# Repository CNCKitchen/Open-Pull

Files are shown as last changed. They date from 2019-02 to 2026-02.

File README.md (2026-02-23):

# Open-Pull

DIY universal testing machine files (mechanics, electronics, firmware, and browser control UI).

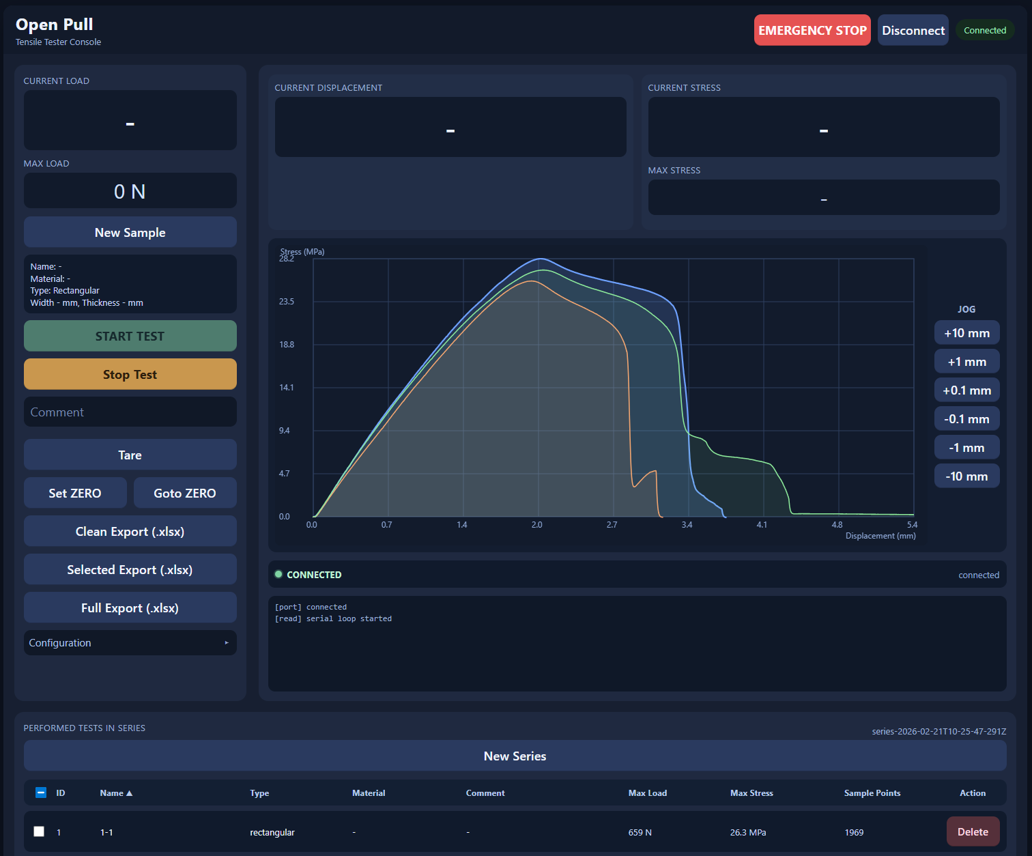
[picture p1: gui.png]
Open-Pull Web GUI


Watch the project video: https://youtu.be/uvn-J8CbtzM

Support: [Patreon](https://www.patreon.com/cnckitchen) · [PayPal](https://www.paypal.me/CNCKitchen)

## Safety + Disclaimer

Open-Pull is a DIY machine and **not certified professional test equipment**.

- Use safety glasses and shielding.
- Keep hands, loose clothing, and tools away from moving parts.
- Verify load limits for frame, grips, motors, drivers, and load cell.
- Validate calibration before collecting any meaningful data.

You are responsible for safe operation and for verifying all measurements.

## Repository Contents

- `Arduino/OpenPull/OpenPull.ino` – firmware for Arduino Nano-compatible target.
- `WebGUI/` – browser-based control and data export app (Web Serial).
- `Electronics/Eagle-Files/` – schematic/board files and custom Eagle library.
- `CAD/TestMachine/` – machine assembly files (`.f3d`, `.step`) and parts.
- `CAD/Specimens/` – specimen CAD models.
- `Documents/DataAnalysis.xlsx` – spreadsheet-based analysis template.
- `Documents/exportTrackingPoints.py` – Blender tracking marker export helper.

## Hardware Overview

Typical build components include:

- 2× geared NEMA17 steppers
- 2× trapezoidal lead screws and nuts
- linear guidance/bearings/couplers/frame hardware
- Arduino Nano
- 2× A4988 stepper drivers
- HX711 load-cell amplifier + suitable load cell
- 24V supply and cooling

Use the CAD and electronics folders as the source of truth for your specific build variant.

## Firmware

Firmware location: `Arduino/OpenPull/OpenPull.ino`

### Key behavior

- Non-blocking serial command handling.
- Timer-driven step generation.
- Ramped acceleration/deceleration.
- Median + exponential filtering for load values.
- Automatic break detection (optional) with optional quick re-tare.
- Persistent config in EEPROM (speeds, accel, gain, sample rate, etc.).

### Firmware dependencies

- Arduino `HX711` library by Bogde (`bogde/HX711`).
- Arduino `EEPROM` (built-in).

### Upload basics

1. Open `Arduino/OpenPull/OpenPull.ino` in Arduino IDE.
2. Select your board/port.
3. Ensure the HX711 library is installed.
4. Compile and upload.

Serial settings: **115200 baud**, newline-terminated commands.

## Command Reference

All commands are ASCII lines terminated with `\n`.

### Motion + test control

- `M10 [S1]` – start slow test. `S1` enables slow-test break-speedup mode.
- `M11` – manual mode / stop active test.
- `M12` – tare load cell.
- `M13` – Young's/modulus profile (slow phase then fast phase).
- `M14` – start fast test.
- `M15` – emergency stop.
- `M20` – set current position as displacement zero.
- `M21` – move to displacement zero.
- `M22 <delta_mm>` – relative jog move.

### Configuration

- `M40 <mm_per_min>` – set slow test speed.
- `M41 <mm_per_min>` – set fast test speed.
- `M42 <mm_per_s2>` – set acceleration.
- `M43 <gain>` – set load-cell gain (**only during unlocked gain window**).
- `M44 <Hz>` – set sample rate.
- `M45 <mm_per_min>` – set manual slow jog speed.
- `M46 <mm_per_min>` – set manual fast jog speed.
- `M47 <N>` – set preload target for slow-test start sequence.
- `M48 <0..1>` – set load filter alpha.
- `M49 <0|1>` – disable/enable auto break detection.
- `M50` – report current config.
- `M51 <0|1>` – disable/enable tare-after-break.
- `M53` – arm gain write window (30s wait + 30s allowed write window).

## Serial Protocol

Firmware emits CSV-like tagged lines:

- `DATA,<timestamp_ms>,<load_N>,<step_position>,<displacement_mm>,<mode>,<speed_steps_per_s>`
- `STATUS,<timestamp_ms>,<code>,<message>`
- `ACK,<timestamp_ms>,<command>,<message>`
- `CFG,<timestamp_ms>,<slow_mm_min>,<fast_mm_min>,<accel_mm_s2>,<gain>,<sample_hz>,<manual_slow_mm_min>,<manual_fast_mm_min>,<preload_n>,<alpha>,<auto_break>,<tare_after_break>`

Mode values:

- `1` slow test
- `2` manual
- `3` fast test
- `4` Young's test
- `5` go-to-zero
- `6` relative move

## Web GUI

GUI location: `WebGUI/index.html`

### Features

- Web Serial connect/disconnect.
- Guided workflow: create series → prepare sample → start test.
- Clean status row with color-coded state indicator (e.g. ready, pretension, moving to zero, testing, break detected, test stopped) and detailed status text.
- Live chart with selectable axes:
	- X: time or displacement
	- Y: force or stress
- Per-test metadata (name/material/comment/type/geometry).
- Performed-tests table with sortable columns: ID, name, type, material, comment, max load, max stress, sample points.
- Per-test delete action in the series list.
- Overlay management via per-test checkboxes + master checkbox (all eligible tests on/off).
- Duplicate-name warning when preparing a new sample.
- Manual jog buttons (`±0.1`, `±1`, `±10 mm`).
- Tare, zero, goto-zero, stop, and emergency stop.
- Firmware config controls (preload, alpha, sample rate, manual speeds, accel, gain unlock/set, break options).
- Export to XLSX (clean, selected, and full variants), each with configuration and summary data.
- Local persistence of series state in browser `localStorage`.

### Browser requirements

- Chromium-based browser with Web Serial support (Chrome/Edge).
- USB serial permission to the controller.
- Internet connection if loading the bundled CDN XLSX script as-is.

### Running

1. Open `WebGUI/index.html` in a compatible browser.
2. Click **Connect** and choose the Open-Pull serial port.
3. Click **New Series**.
4. Click **New Sample**, fill sample details, confirm.
5. Set speed/config as needed.
6. Click **START TEST**.
7. Stop with **Stop Test** (`M11`) or **EMERGENCY STOP** (`M15`) if required.
8. Export results with **Clean Export (.xlsx)**, **Selected Export (.xlsx)**, or **Full Export (.xlsx)**.

## Data Export

WebGUI provides three spreadsheet exports:

- **Clean Export (.xlsx)**
	- Organized two-column blocks per test (displacement vs stress/force)
	- Uses the current series-list sort order
	- Includes `Summary` and `Configuration` sheets
	- Intended for quick plotting and reporting

- **Selected Export (.xlsx)**
	- Same layout as clean export, but only for tests selected in the series list checkbox column
	- Uses the current series-list sort order
	- Includes `Summary` and `Configuration` sheets

- **Full Export (.xlsx)**
	- Flat table with full per-sample rows
	- Includes timestamps, load, displacement, mode, speed, and metadata
	- Includes `Summary` and `Configuration` sheets

The `Summary` sheet mirrors the performed-tests overview (ID, name, type, material, comment, max load, max stress, sample points).

`Documents/DataAnalysis.xlsx` can be used for additional analysis workflows.

## Optical Tracking Helper

`Documents/exportTrackingPoints.py` exports Blender tracking marker coordinates to CSV files.

Update the output path inside the script to match your system before running.

## Troubleshooting

- **No serial connection in browser:** use Chrome/Edge and verify Web Serial support/permissions.
- **`hx711_not_ready` status:** check HX711 wiring, power, and load-cell connection.
- **Cannot set gain:** send/use `M53`, wait for unlock delay, then send `M43 <gain>` within the allowed window.
- **Unexpected force spikes/noise:** verify grounding, shielded wiring, stable power, and tuning of filter alpha/sample rate.
- **Inconsistent displacement zero:** run `M20` at known reference and use `M21` for repeatability checks.

## License

This repository is licensed under **GNU GPL v3.0**. See `LICENSE`.

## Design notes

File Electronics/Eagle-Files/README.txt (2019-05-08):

Version 1:
Carrier PCB for:
	- Arduino Nano,
	- Sparkfun HX711 Weight Cell Amplifier
	- 2x Polulu Stepper Motor Driver
	- 2x 100uF smoothing Capacitor for Stepper Motor Drivers either SMD or THT
	- a on board sync-led either THT or SMD
	- IMPORTANT NOTICE: this is the 1st version of the board and may still contain errors!!! 
	  ALSO: only use either an SMD or a THT capacitor same goes for the onboard LED.
	
Parts:
	- Arduino Nano: original or clone will do
	- Sparkfun HX711: https://www.sparkfun.com/products/13879
	- Polulu A4988 Stepper Motor Drivers: https://www.pololu.com/product/1182
	- R1/R2: 330 Ohm Resistor: 1/4W THT or 0805 SMD
	- LED1/LED2: 3.5mm LED or 0805 LED color doesn't matter (ajust resistor for blue)
	- C1/C3 & C2/C4: Any fitting Capcitor will do, I designed around these:
			- THT: WURTH ELECTRONIC 860020674015
			- SMD: WURTH ELECTRONIC 865060653010
	- CELL-0, 1, 2, X1: WURTH ELECTRONIC 691214110002
	- CON1, CON2, CON3: Any 100mil/1.27mm pitch connector that fits your needs. You can als solder directly into the holes.

Board by Felix Hillebrand 97hilfel(at)gmail.com
Feel free to use and share.

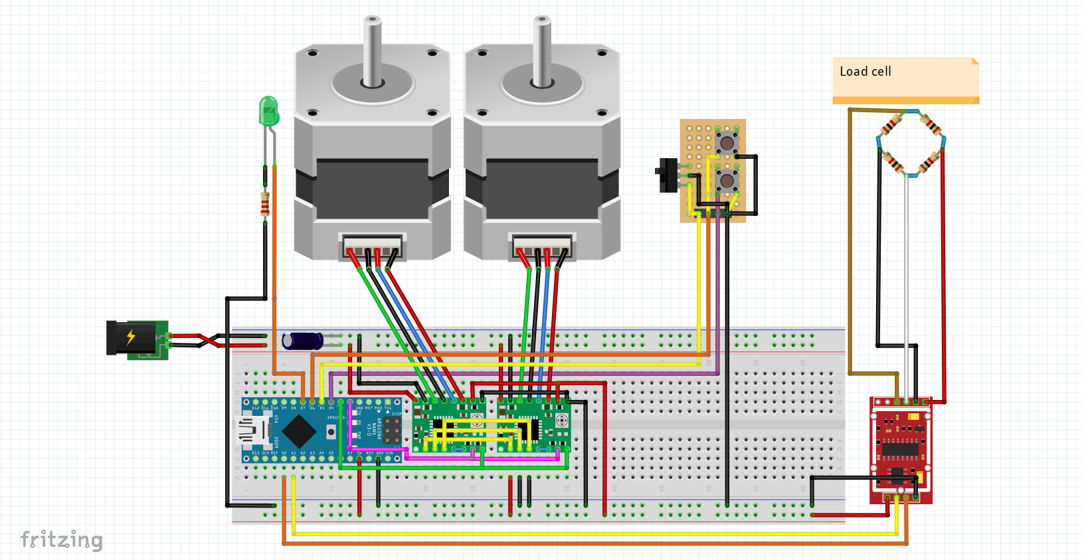
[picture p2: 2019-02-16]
Electronics/schematics.png

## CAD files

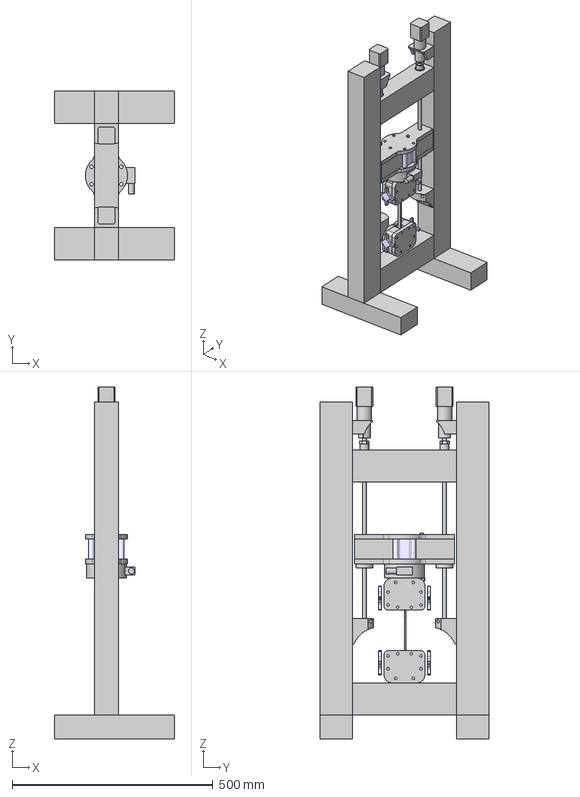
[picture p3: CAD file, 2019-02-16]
CAD/TestMachine/OpenPull-assembly.step
300.0 x 420.0 x 877.0 mm
SpecimenHolder_OuterPart x 2
ClampingPlate x 4
einschlagmutter_M8 x 2
SpecimenHolder_OuterPart (1) x 2
Knob x 2
608 bearing x 4
TestSpecimen_ISO-527-2-1A
nut_flange x 2
leadScrew x 2
Clutch x 2
nut x 2
stepper x 2
stepperBracket x 2
lowerBearing x 2
3200 2RS - bearing x 2
6202-Z bearing x 2
trapezoidalNut1 x 2
trapezoidalNut2 x 2
upperMemberSupport (1)
upperMember
upperMemberSupport
loadCell
M8x120
spacer x 2
foot x 2
sidePillars x 2
mostUpperMember
lowerMember

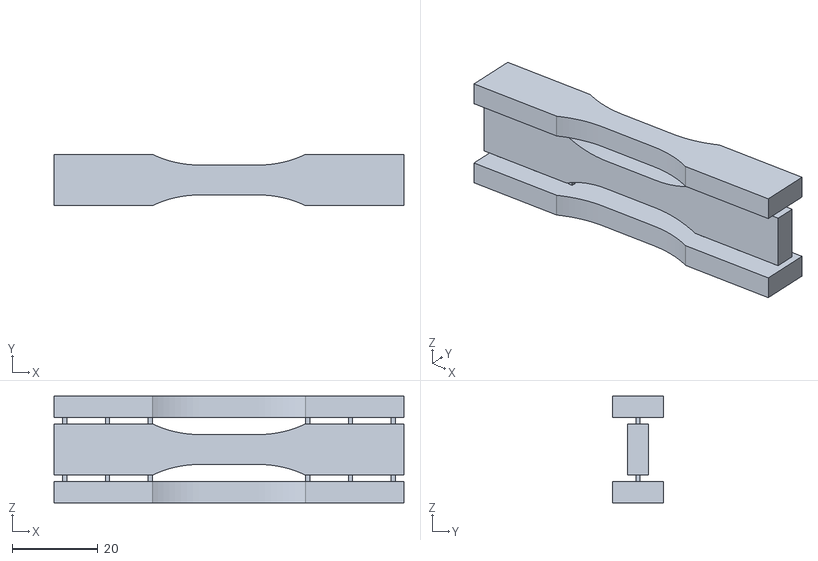
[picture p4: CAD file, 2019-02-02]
CAD/Specimens/TensileSpecimen_LayerAdhesion_x3.stl
81.8 x 12.0 x 25.0

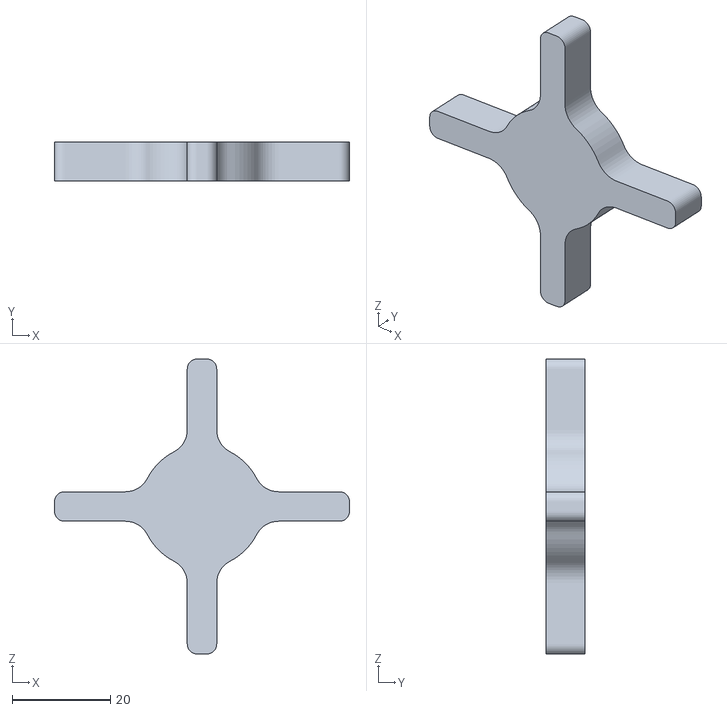
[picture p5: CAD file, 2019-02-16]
CAD/TestMachine/IndividualParts/TensileTestMachine v6_TensileTestMachine v6_ClampingYaw1_1_Knob_1_Body1_Knob_1.stl
60.0 x 8.00 x 60.0

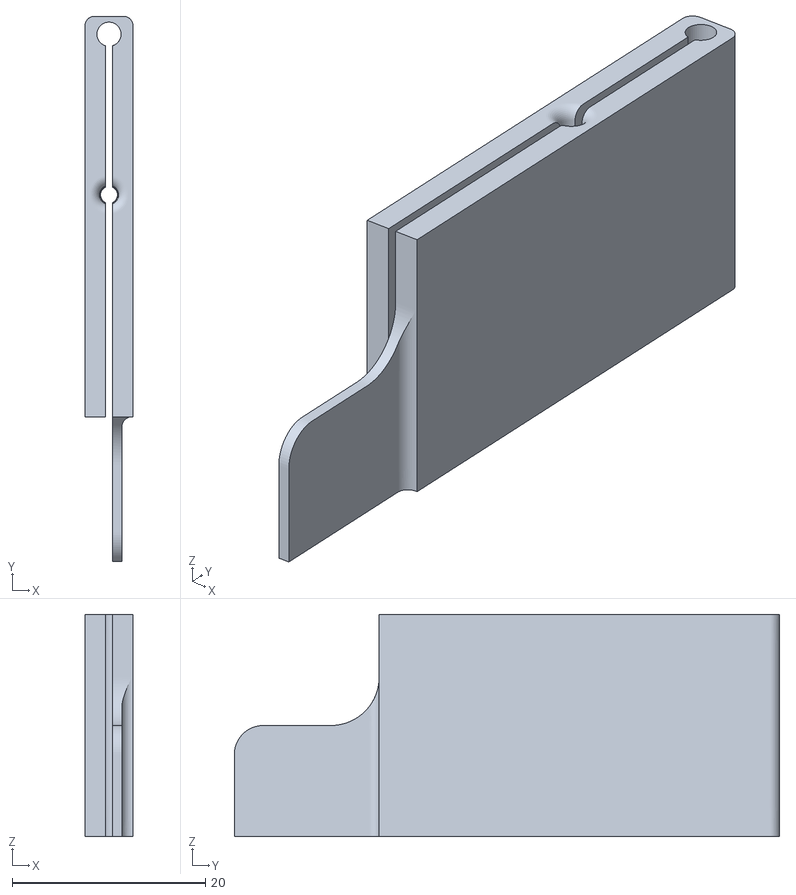
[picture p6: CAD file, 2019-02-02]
CAD/Tools/FilamentClamp.stl
5.00 x 56.5 x 23.0

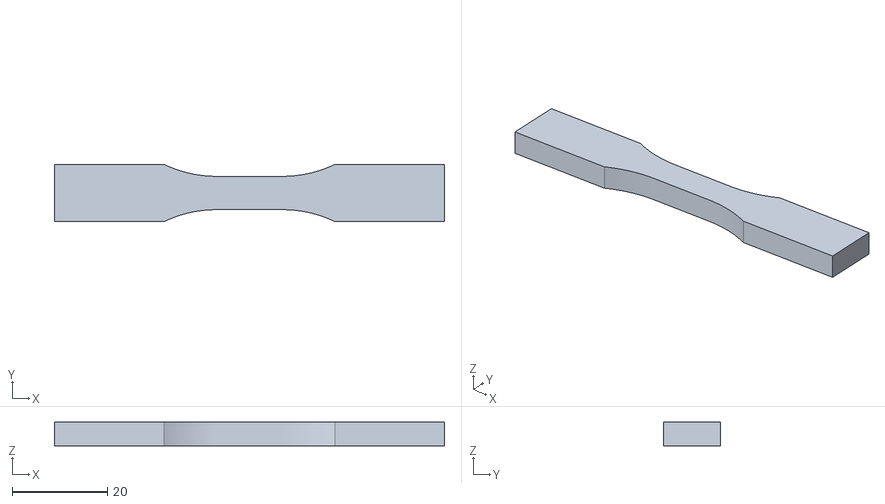
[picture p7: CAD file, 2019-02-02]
CAD/Specimens/TensileSpecimen_LayerAdhesion.stl
81.8 x 12.0 x 5.00

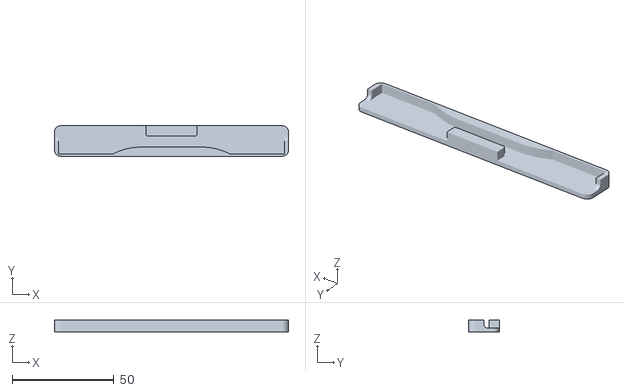
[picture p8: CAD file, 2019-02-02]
CAD/Tools/DistanceGauge.stl
115.0 x 15.0 x 6.00

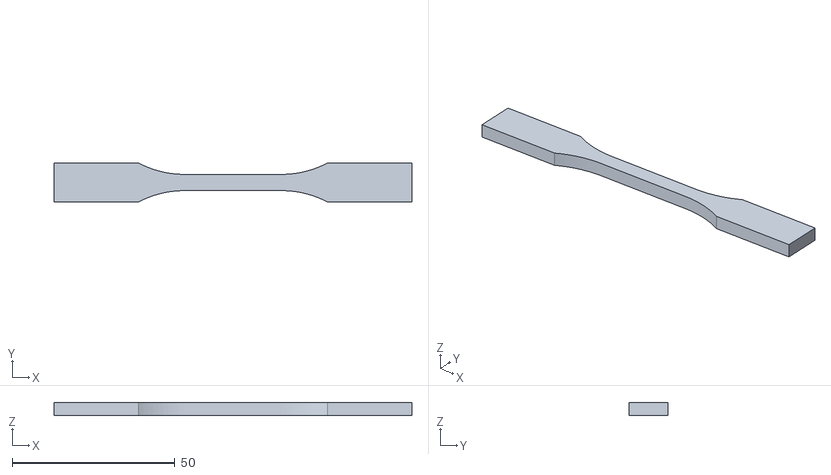
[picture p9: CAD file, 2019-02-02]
CAD/Specimens/TensileSpecimen_ISO-527-2-1BA.stl
110.0 x 11.9 x 4.00

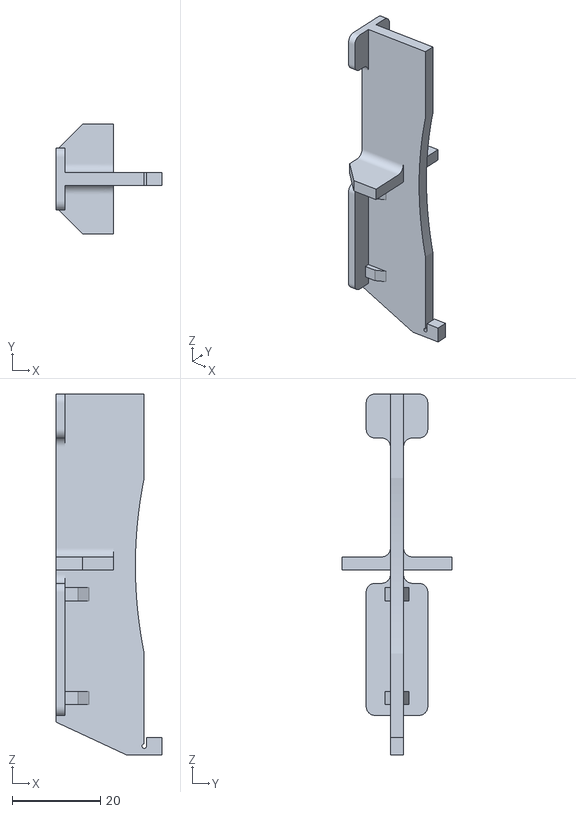
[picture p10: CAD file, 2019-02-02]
CAD/Tools/LayerAdhesionSpecimenAlignmentTool.stl
24.0 x 25.0 x 82.0

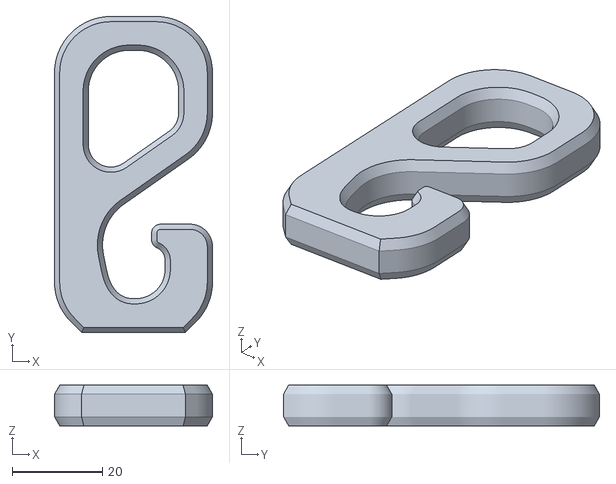
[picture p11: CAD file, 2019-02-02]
CAD/Specimens/testHook_noSlots.stl
35.0 x 70.0 x 9.00

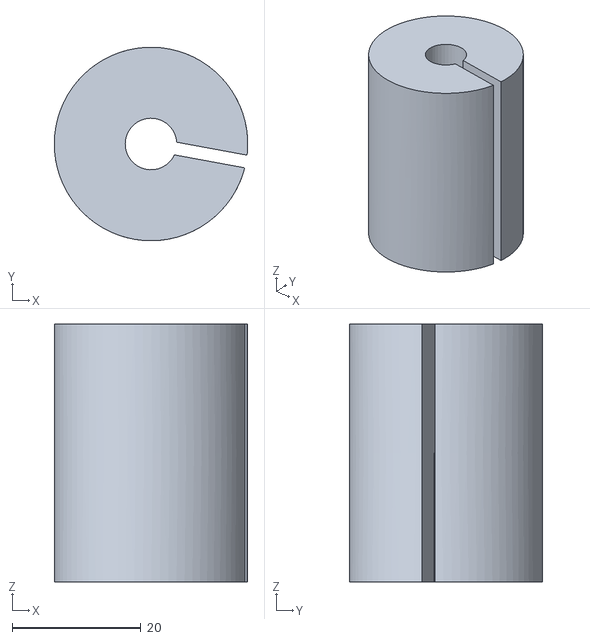
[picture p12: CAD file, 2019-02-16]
CAD/TestMachine/IndividualParts/TensileTestMachine v6_TensileTestMachine v6_drive_2_Clutch_1_Body1_Clutch_1.stl
30.0 x 30.0 x 40.0

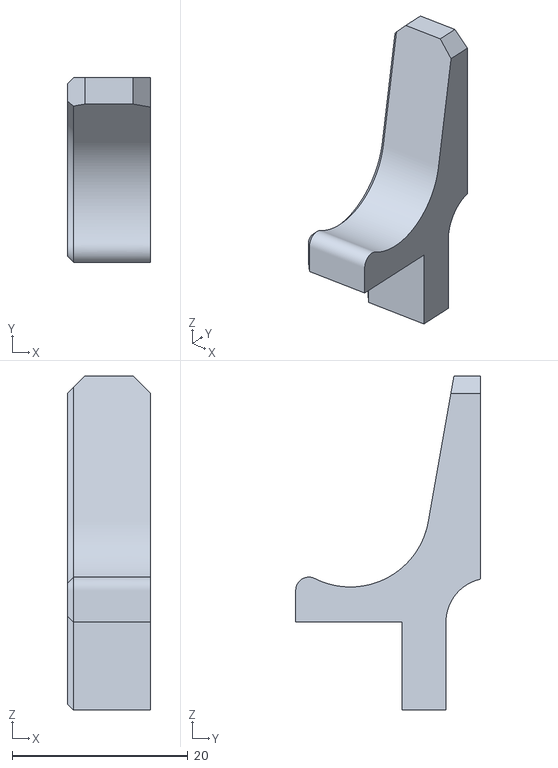
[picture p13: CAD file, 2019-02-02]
CAD/Tools/TensileSpecimenAlignmentTool.stl
9.50 x 21.0 x 38.0

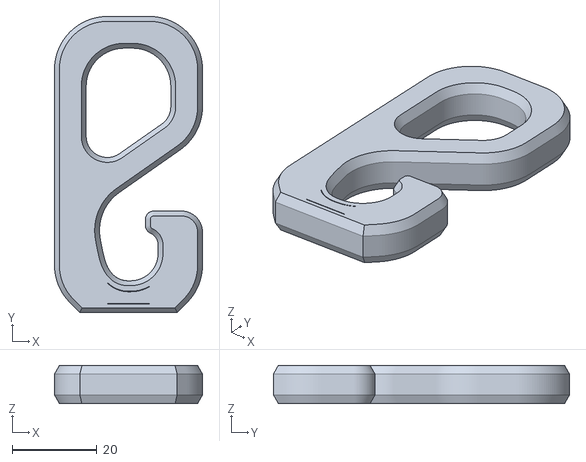
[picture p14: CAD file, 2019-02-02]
CAD/Specimens/testHook.stl
35.0 x 70.0 x 9.00

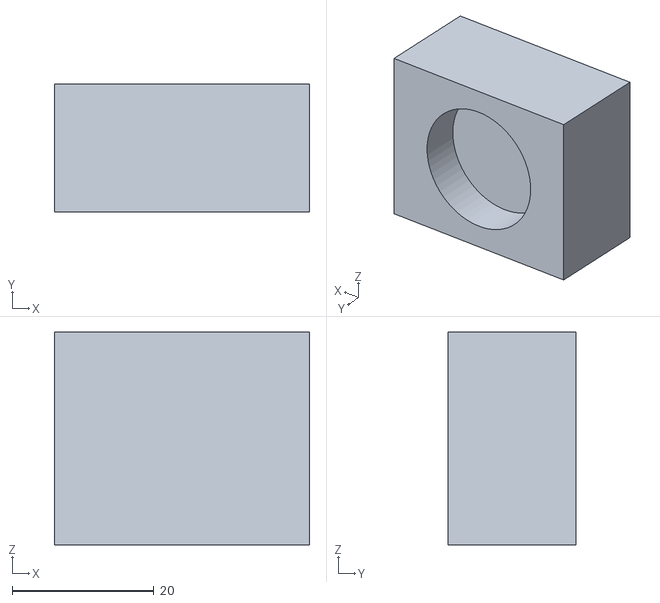
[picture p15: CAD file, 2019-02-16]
CAD/TestMachine/IndividualParts/TensileTestMachine v6_TensileTestMachine v6_ClampingYaw1_2_ClampingPlate_1_Body1_ClampingPlate.stl
36.0 x 18.0 x 30.0

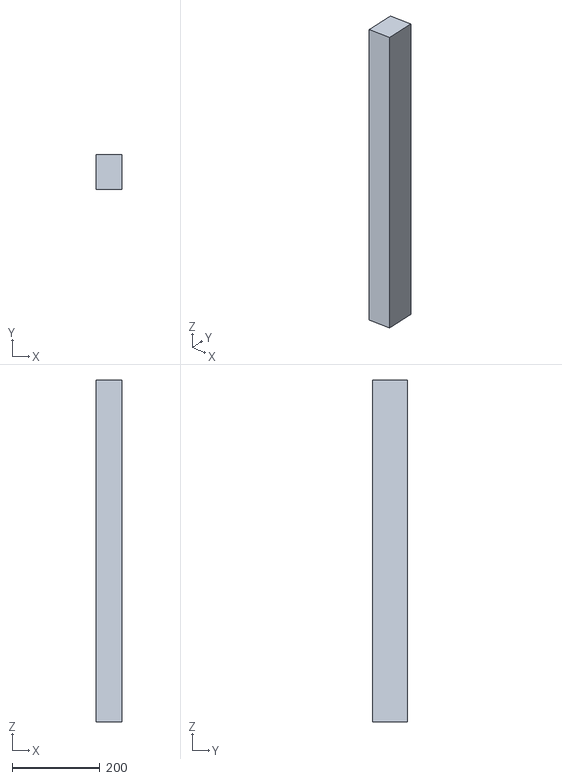
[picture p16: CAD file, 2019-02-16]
CAD/TestMachine/IndividualParts/TensileTestMachine v6_TensileTestMachine v6_frame_1_sidePillars_1_Body1_sidePillars.stl
60.0 x 80.0 x 780.0

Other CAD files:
CAD/TestMachine/IndividualParts/TensileTestMachine v6_TensileTestMachine v6_ClampingYaw1_1_Body1_.stl
CAD/TestMachine/IndividualParts/TensileTestMachine v6_TensileTestMachine v6_ClampingYaw1_2_ClampingPlate_1_Body1_ClampingPlate_2.stl
CAD/TestMachine/IndividualParts/TensileTestMachine v6_TensileTestMachine v6_drive_1_6202-Z bearing_1_Body2_6202-Z bearing.stl
CAD/TestMachine/IndividualParts/TensileTestMachine v6_TensileTestMachine v6_ClampingYaw1_1_ClampingPlate_2_Body1_ClampingPlate_3.stl
CAD/TestMachine/IndividualParts/TensileTestMachine v6_TensileTestMachine v6_ClampingYaw1_1_608 bearing_1_Body1_608 bearing.stl
CAD/TestMachine/IndividualParts/TensileTestMachine v6_TensileTestMachine v6_ClampingYaw1_1_608 bearing_1_Body1_608 bearing_1.stl
CAD/TestMachine/IndividualParts/TensileTestMachine v6_TensileTestMachine v6_ClampingYaw1_1_608 bearing_1_Body1_608 bearing_2.stl
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

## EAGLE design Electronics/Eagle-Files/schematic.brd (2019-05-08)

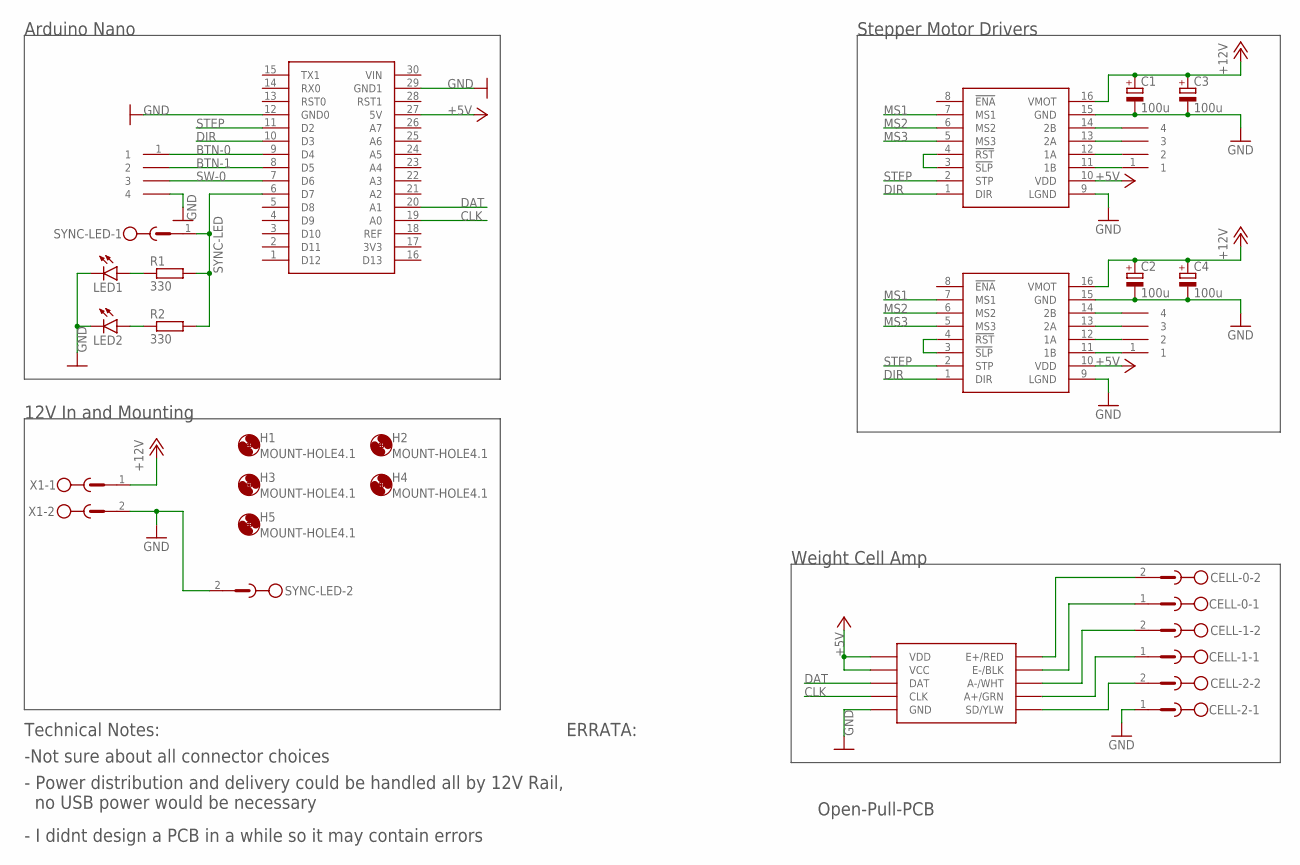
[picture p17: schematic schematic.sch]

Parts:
C1, C2: 100u; 3.5MM-CAP
C3, C4: 100u; CAPAE830X1050
CELL-0, CELL-1, CELL-2: MSTBV2
CON1, CON2, CON3: CON-4GENERIC; HDRV4W64P254_1X4_1016X508X838B
DRIVER1, DRIVER2: A4988-MODULE; POLULU-A4988
H1, H2, H3, H4, H5: MOUNT-HOLE4.1; 4,1
LED1: LEDCHIP-LED0805; CHIP-LED0805
LED2: LED3MM
MODULE1: HX711-MODULE; SPARKFUN-HX711
NANO1: ARDUINO-NANO
R1: 330; R0805
R2: 330; 0207/2V
SYNC-LED: MSTBV2
X1: MSTBV2

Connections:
3V3: NANO1.17 (3V3)
+5V: DRIVER1.10 (VDD), DRIVER2.10 (VDD), MODULE1.VCC, MODULE1.VDD, NANO1.27 (5V)
+12V: C1.+, C2.+, C3.1 (+), C4.1 (+), DRIVER1.16 (VMOT), DRIVER2.16 (VMOT), X1.1
BTN-0: CON3.1, NANO1.9 (D4)
BTN-1: CON3.2, NANO1.8 (D5)
CLK: MODULE1.CLK, NANO1.19 (A0)
DAT: MODULE1.DAT, NANO1.20 (A1)
DIR: DRIVER1.1 (DIR), DRIVER2.1 (DIR), NANO1.10 (D3)
GND: C1.-, C2.-, C3.2 (-), C4.2 (-), CELL-2.1, CON3.4, DRIVER1.9 (LGND), DRIVER1.15 (GND), DRIVER2.9 (LGND), DRIVER2.15 (GND), LED1.C, LED2.K (C), MODULE1.GND, NANO1.12 (GND0), NANO1.29 (GND1), SYNC-LED.2, X1.2
MS1: DRIVER1.7 (MS1), DRIVER2.7 (MS1)
MS2: DRIVER1.6 (MS2), DRIVER2.6 (MS2)
MS3: DRIVER1.5 (MS3), DRIVER2.5 (MS3)
unnamed: DRIVER2.3 (!SLP), DRIVER2.4 (!RST)
unnamed: DRIVER1.3 (!SLP), DRIVER1.4 (!RST)
unnamed: CON1.1, DRIVER1.11 (1B)
unnamed: CON1.2, DRIVER1.12 (1A)
unnamed: CON1.3, DRIVER1.13 (2A)
unnamed: CON1.4, DRIVER1.14 (2B)
unnamed: CON2.1, DRIVER2.11 (1B)
unnamed: CON2.2, DRIVER2.12 (1A)
unnamed: CON2.3, DRIVER2.13 (2A)
unnamed: CON2.4, DRIVER2.14 (2B)
unnamed: CELL-0.2, MODULE1.RED (E+/RED)
unnamed: CELL-0.1, MODULE1.BLK (E-/BLK)
unnamed: CELL-1.2, MODULE1.WHT (A-/WHT)
unnamed: LED1.A, R1.1
unnamed: CELL-1.1, MODULE1.GRN (A+/GRN)
unnamed: LED2.A, R2.1
unnamed: CELL-2.2, MODULE1.YEL (SD/YLW)
STEP: DRIVER1.2 (STP), DRIVER2.2 (STP), NANO1.11 (D2)
SW-0: CON3.3, NANO1.7 (D6)
SYNC-LED: NANO1.6 (D7), R1.2, R2.2, SYNC-LED.1
VIN: NANO1.30 (VIN)

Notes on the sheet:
Open-Pull-PCB
Arduino Nano
Stepper Motor Drivers
Weight Cell Amp
12V In and Mounting
Technical Notes:
-Not sure about all connector choices
- Power distribution and delivery could be handled all by 12V Rail, no USB power would be necessary
- I didnt design a PCB in a while so it may contain errors
ERRATA:

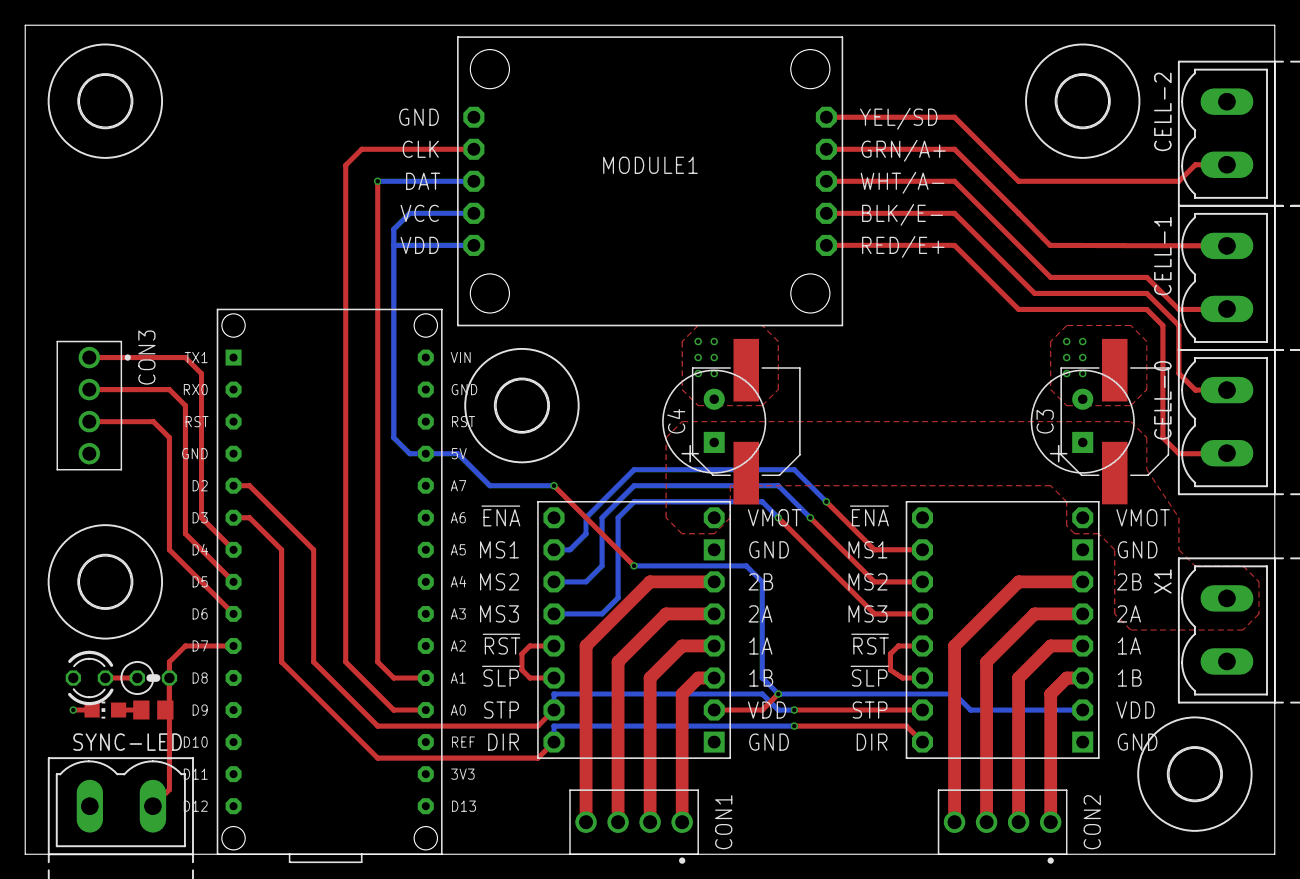
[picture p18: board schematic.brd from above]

Board: 2 copper layers, 99.0 x 65.7 mm, 25 parts (0 on the bottom side), 31 nets.

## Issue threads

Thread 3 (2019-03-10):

Interest in refactoring the code to use interrupts for steppers?

jgill88, 2019-03-10:
Watching the video of this, at around 10:30, you mention the issue of the stepper motors stopping when measurements are taken.

Refactoring the code to use interrupts to drive the stepper motors would probably fix this. If you're interested in that, I would be willing to refactor it. Let me know!

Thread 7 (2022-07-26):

Leadscrew Locknut

S1L3NTANG3L, 2022-07-26:
I am unable to find the locknut for the leadscrews as per the design file. Is it custom made or does someone have a link for me where I can purchase it.

PigeonFX, 2022-07-26:
Do you mean the 2x Trapezoidal Nut 10x2?

If so, 98% sure these are the ones I ordered.

https://www.ebay.co.uk/itm/273030924681

S1L3NTANG3L, 2022-07-26:
A lovely thank you very much!

S1L3NTANG3L, 2022-07-26:
So that seller doesn't ship to me :'( Do you think it would work if I just use the brass ones and machine the flange off?

CNCKitchen, 2022-07-26:
Should definitely work as well and might even be cheaper. You might even get around to printing one out of PLA, depending on the loads you expect.

S1L3NTANG3L, 2022-07-26:
I'm printing all the plastic parts from PETG but yeah I was scared about the two lock nuts, I'll try the brass method and post back here if it works as there is no reason they won't as the moving head uses them(In your video) and they didn't strip out so I'm hopeful;

Closed 2022-07-26.

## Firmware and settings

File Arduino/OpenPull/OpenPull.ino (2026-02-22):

/*########################################
  ##### OPEN PULL
  ##### DIY Universal Test Machine
  ##### V2.1 (non-blocking + ramped motion)
  ##### Stefan Hermann aka CNC Kitchen
  ##### https://www.youtube.com/cnckitchen
  ##### Libraries:
  ##### HX711 by Bogde: https://github.com/bogde/HX711
  ########################################*/

#include <HX711.h>
#include <EEPROM.h>
#include <string.h>
#include <stdlib.h>
#include <math.h>

////// Load Cell Variables
float gainValue = -875.7f * (1.0f - 0.001f); // CALIBRATION FACTOR
long tareValue = 0;
HX711 loadCell;

////// Stepper / Kinematics
const uint8_t directionPin = 3;
const uint8_t stepPin = 2;
const uint8_t speedPin = 5;
const uint8_t upPin = 4;
const uint8_t downPin = 6;
const uint8_t led1Pin = 7;

const float stepsPerMM = 200.0f * 2.0f * (13.0f + 212.0f / 289.0f) / 2.0f; // Steps per rev * Microstepping * Gear reduction / Pitch
const float baseTestSpeedSps = stepsPerMM / 60.0f; // 1 mm/min

// Legacy jog delays mapped to SPS to preserve feel
float jogSlowSps = 1000000.0f / 3000.0f;
float jogFastSps = 1000000.0f / 300.0f;

// Motion profile defaults
float slowTestSps = baseTestSpeedSps;
float fastTestSps = 25.0f * baseTestSpeedSps; // 25 mm/min
float accelSps2 = 4000.0f;
float gotoZeroSps = 8.0f * baseTestSpeedSps;
float preloadN = 2.0f;
float loadFilterAlpha = 0.20f;
bool autoBreakDetectionEnabled = true;
bool tareAfterBreakEnabled = false;
const float gainAbsMin = 100.0f;
const float gainAbsMax = 5000.0f;
const unsigned long gainWriteDelayMs = 30000UL;
const unsigned long gainWriteWindowMs = 30000UL;
const unsigned long tareAfterBreakDelayMs = 2000UL;

// Timing
const unsigned long yMTestTimeMs = 30000UL;
const unsigned long accelUpdateIntervalUs = 5000UL;
unsigned long sampleIntervalUs = 12500UL; // target 80 Hz stream
const unsigned long hx711MissingDataTimeoutMs = 1500UL;
const float hx711UpwardSpikeThresholdN = 300.0f;
const uint8_t hx711MedianWindowSize = 5;
const float preloadToleranceN = 0.15f;
const float breakDetectNegativeThresholdN = -0.20f;
const uint8_t breakDetectConsecutiveSamples = 10;
const float breakDetectMinPeakForceN = 0.50f;

// Mode definitions
const byte MODE_TEST_SLOW = 1;
const byte MODE_MANUAL = 2;
const byte MODE_TEST_FAST = 3;
const byte MODE_YOUNGS = 4;
const byte MODE_GOTO_ZERO = 5;
const byte MODE_RELATIVE_MOVE = 6;

volatile bool motionEnabled = false;
volatile bool stepDirLow = true;
volatile long stepPosition = 0;
volatile uint16_t stepIntervalTicks = 4000; // 2000us default @ prescaler 8 (0.5us/tick)

byte mode = MODE_MANUAL;
byte modeAddition = 0;

float targetSpeedSps = 0.0f;
float currentSpeedSps = 0.0f;
float maxForce = 0.0f;
float loweringCounter = 0.0f;
float lastLoadValue = 0.0f;
float lastRawLoadValue = 0.0f;
bool hasLoadSample = false;
bool hasFilteredLoadSample = false;
float hx711RawWindow[hx711MedianWindowSize];
uint8_t hx711RawWindowCount = 0;
uint8_t hx711RawWindowIndex = 0;
long zeroStepOffset = 0;
long relativeMoveTargetStep = 0;
float relativeMoveSpeedSps = 0.0f;
uint8_t negativeLoadStreak = 0;
bool delayedStartPending = false;
byte delayedStartStage = 0;
unsigned long delayedStartStageMs = 0;
byte delayedStartMode = MODE_TEST_SLOW;
byte delayedStartModeAddition = 0;
const byte START_STAGE_WAIT_BEFORE_TARE = 0;
const byte START_STAGE_WAIT_AFTER_TARE = 1;
const byte START_STAGE_PRELOAD_APPROACH = 2;
const byte START_STAGE_WAIT_AFTER_PRELOAD = 3;
const byte START_STAGE_WAIT_AFTER_SECOND_TARE = 4;
unsigned long startTimeMs = 0;
unsigned long lastSampleUs = 0;
unsigned long lastAccelUpdateUs = 0;
unsigned long lastHx711WarnMs = 0;
unsigned long lastHx711DataMs = 0;
bool debug = false;
bool gainWriteArmed = false;
unsigned long gainWriteAllowedFromMs = 0;
unsigned long gainWriteAllowedUntilMs = 0;
bool quickTareAfterBreakPending = false;
unsigned long quickTareAfterBreakAtMs = 0;

char serialLine[64];
uint8_t serialLineIndex = 0;

void setupTimer1();
void setDirectionLow(bool low);
void setStepIntervalFromSpeed(float speedSps);
void setMotionEnabled(bool enabled);
void enterManualMode();
void emitStatus(const __FlashStringHelper *code, const __FlashStringHelper *message);
void emitAck(const __FlashStringHelper *command, const __FlashStringHelper *message);
void processSerial();
void processCommand(char *line);
void updateModeAndTargets();
void updateAcceleration();
void sampleAndStream();
float getDisplacementMm();
void performTare();
void performQuickTare();
void emitHx711NotReady();
void loadConfigFromEeprom();
void saveConfigToEeprom();
void emitConfig();
float computeMedian(const float *values, uint8_t count);
float getMedianFilteredLoad(float measuredLoad);
bool isGainPlausible(float gain);
bool isGainWriteWindowActive();

struct PersistedConfig {
  uint16_t magic;
  uint8_t version;
  float slowMmPerMin;
  float fastMmPerMin;
  float accelMmPerS2;
  float gain;
  float sampleRateHz;
  float manualSlowMmPerMin;
  float manualFastMmPerMin;
  float preloadN;
  float loadFilterAlpha;
  uint8_t autoBreakDetectionEnabled;
  uint8_t tareAfterBreakEnabled;
};

const uint16_t persistedConfigMagic = 0x504FULL;
const uint8_t persistedConfigVersion = 4;

ISR(TIMER1_COMPA_vect) {
  if (!motionEnabled) {
    return;
  }
  digitalWrite(stepPin, HIGH);
  digitalWrite(stepPin, LOW);
  if (stepDirLow) {
    stepPosition++;
  } else {
    stepPosition--;
  }
}

void setup() {
  Serial.begin(115200);

  pinMode(directionPin, OUTPUT);
  pinMode(stepPin, OUTPUT);
  digitalWrite(directionPin, LOW);
  digitalWrite(stepPin, LOW);

  pinMode(upPin, INPUT);
  digitalWrite(upPin, HIGH);

  pinMode(downPin, INPUT);
  digitalWrite(downPin, HIGH);

  pinMode(speedPin, INPUT);
  digitalWrite(speedPin, HIGH);

  pinMode(led1Pin, OUTPUT);
  digitalWrite(led1Pin, LOW);

  loadCell.begin(A0, A1);
  loadConfigFromEeprom();
  lastHx711DataMs = millis();
  setupTimer1();
  performTare();
  lastAccelUpdateUs = micros();
  lastSampleUs = micros();
  emitStatus(F("BOOT"), F("ready"));
}

void saveConfigToEeprom() {
  PersistedConfig config;
  config.magic = persistedConfigMagic;
  config.version = persistedConfigVersion;
  config.slowMmPerMin = (slowTestSps / stepsPerMM) * 60.0f;
  config.fastMmPerMin = (fastTestSps / stepsPerMM) * 60.0f;
  config.accelMmPerS2 = accelSps2 / stepsPerMM;
  config.gain = gainValue;
  config.sampleRateHz = 1000000.0f / (float)sampleIntervalUs;
  config.manualSlowMmPerMin = (jogSlowSps / stepsPerMM) * 60.0f;
  config.manualFastMmPerMin = (jogFastSps / stepsPerMM) * 60.0f;
  config.preloadN = preloadN;
  config.loadFilterAlpha = loadFilterAlpha;
  config.autoBreakDetectionEnabled = autoBreakDetectionEnabled ? 1 : 0;
  config.tareAfterBreakEnabled = tareAfterBreakEnabled ? 1 : 0;
  EEPROM.put(0, config);
}

void loadConfigFromEeprom() {
  PersistedConfig config;
  EEPROM.get(0, config);

  if (config.magic != persistedConfigMagic || config.version != persistedConfigVersion) {
    saveConfigToEeprom();
    emitStatus(F("CFG"), F("eeprom_invalid_defaults_saved"));
    return;
  }

  if (isfinite(config.slowMmPerMin) && config.slowMmPerMin > 0.01f) {
    slowTestSps = (config.slowMmPerMin / 60.0f) * stepsPerMM;
  }

  if (isfinite(config.fastMmPerMin) && config.fastMmPerMin > 0.01f) {
    fastTestSps = (config.fastMmPerMin / 60.0f) * stepsPerMM;
  }

  if (isfinite(config.accelMmPerS2) && config.accelMmPerS2 > 0.01f) {
    accelSps2 = config.accelMmPerS2 * stepsPerMM;
  }

  if (isGainPlausible(config.gain)) {
    gainValue = config.gain;
  }

  if (isfinite(config.sampleRateHz) && config.sampleRateHz > 0.1f) {
    unsigned long intervalUs = (unsigned long)(1000000.0f / config.sampleRateHz);
    if (intervalUs < 1000UL) {
      intervalUs = 1000UL;
    }
    sampleIntervalUs = intervalUs;
  }

  if (isfinite(config.manualSlowMmPerMin) && config.manualSlowMmPerMin > 0.01f) {
    jogSlowSps = (config.manualSlowMmPerMin / 60.0f) * stepsPerMM;
  }

  if (isfinite(config.manualFastMmPerMin) && config.manualFastMmPerMin > 0.01f) {
    jogFastSps = (config.manualFastMmPerMin / 60.0f) * stepsPerMM;
  }

  if (isfinite(config.preloadN) && config.preloadN >= 0.0f) {
    preloadN = config.preloadN;
  }

  if (isfinite(config.loadFilterAlpha) && config.loadFilterAlpha > 0.0f && config.loadFilterAlpha <= 1.0f) {
    loadFilterAlpha = config.loadFilterAlpha;
  }

  autoBreakDetectionEnabled = config.autoBreakDetectionEnabled != 0;
  tareAfterBreakEnabled = config.tareAfterBreakEnabled != 0;
  emitStatus(F("CFG"), F("eeprom_loaded"));
}

void emitConfig() {
  Serial.print(F("CFG,"));
  Serial.print(millis());
  Serial.print(',');
  Serial.print((slowTestSps / stepsPerMM) * 60.0f, 3);
  Serial.print(',');
  Serial.print((fastTestSps / stepsPerMM) * 60.0f, 3);
  Serial.print(',');
  Serial.print(accelSps2 / stepsPerMM, 3);
  Serial.print(',');
  Serial.print(gainValue, 3);
  Serial.print(',');
  Serial.print(1000000.0f / (float)sampleIntervalUs, 3);
  Serial.print(',');
  Serial.print((jogSlowSps / stepsPerMM) * 60.0f, 3);
  Serial.print(',');
  Serial.print((jogFastSps / stepsPerMM) * 60.0f, 3);
  Serial.print(',');
  Serial.print(preloadN, 3);
  Serial.print(',');
  Serial.print(loadFilterAlpha, 3);
  Serial.print(',');
  Serial.print(autoBreakDetectionEnabled ? 1 : 0);
  Serial.print(',');
  Serial.println(tareAfterBreakEnabled ? 1 : 0);
}

void loop() {
  processSerial();

  if (quickTareAfterBreakPending && mode == MODE_MANUAL && !delayedStartPending && currentSpeedSps < 0.5f) {
    if ((long)(millis() - quickTareAfterBreakAtMs) >= 0) {
      performTare();
      quickTareAfterBreakPending = false;
      emitStatus(F("AUTO"), F("tare_after_break_done"));
    }
  }

  updateModeAndTargets();
  updateAcceleration();
  sampleAndStream();
}

void setupTimer1() {
  noInterrupts();
  TCCR1A = 0;
  TCCR1B = 0;
  TCNT1 = 0;
  OCR1A = stepIntervalTicks;
  TCCR1B |= (1 << WGM12);  // CTC
  TCCR1B |= (1 << CS11);   // prescaler 8 => 0.5us per tick
  TIMSK1 |= (1 << OCIE1A); // compare interrupt
  interrupts();
}

void setDirectionLow(bool low) {
  digitalWrite(directionPin, low ? LOW : HIGH);
  noInterrupts();
  stepDirLow = low;
  interrupts();
}

void setStepIntervalFromSpeed(float speedSps) {
  if (speedSps < 0.1f) {
    speedSps = 0.1f;
  }
  float intervalUs = 1000000.0f / speedSps;
  float ticks = intervalUs * 2.0f; // 0.5us per tick
  if (ticks < 60.0f) {
    ticks = 60.0f;
  }
  if (ticks > 65535.0f) {
    ticks = 65535.0f;
  }
  noInterrupts();
  stepIntervalTicks = (uint16_t)ticks;
  OCR1A = stepIntervalTicks;
  interrupts();
}

void setMotionEnabled(bool enabled) {
  noInterrupts();
  motionEnabled = enabled;
  interrupts();
}

void enterManualMode() {
  mode = MODE_MANUAL;
  modeAddition = 0;
  targetSpeedSps = 0.0f;
  emitStatus(F("MODE"), F("manual"));
}

void emitStatus(const __FlashStringHelper *code, const __FlashStringHelper *message) {
  Serial.print(F("STATUS,"));
  Serial.print(millis());
  Serial.print(',');
  Serial.print(code);
  Serial.print(',');
  Serial.println(message);
}

void emitAck(const __FlashStringHelper *command, const __FlashStringHelper *message) {
  Serial.print(F("ACK,"));
  Serial.print(millis());
  Serial.print(',');
  Serial.print(command);
  Serial.print(',');
  Serial.println(message);
}

void emitHx711NotReady() {
  unsigned long nowMs = millis();
  if ((unsigned long)(nowMs - lastHx711DataMs) < hx711MissingDataTimeoutMs) {
    return;
  }
  if ((unsigned long)(nowMs - lastHx711WarnMs) >= 1000UL) {
    emitStatus(F("ERR"), F("hx711_not_ready"));
    lastHx711WarnMs = nowMs;
  }
}

void performTare() {
  digitalWrite(led1Pin, HIGH);
  unsigned long tareStartMs = millis();
  while (!loadCell.is_ready()) {
    if ((unsigned long)(millis() - tareStartMs) >= 500UL) {
      emitStatus(F("ERR"), F("tare_timeout"));
      digitalWrite(led1Pin, LOW);
      return;
    }
    delay(5);
  }
  tareValue = loadCell.read_average(32);
  hasLoadSample = false;
  hasFilteredLoadSample = false;
  lastLoadValue = 0.0f;
  lastRawLoadValue = 0.0f;
  hx711RawWindowCount = 0;
  hx711RawWindowIndex = 0;
  lastHx711DataMs = millis();
  digitalWrite(led1Pin, LOW);
}

void performQuickTare() {
  digitalWrite(led1Pin, HIGH);
  unsigned long tareStartMs = millis();
  while (!loadCell.is_ready()) {
    if ((unsigned long)(millis() - tareStartMs) >= 300UL) {
      emitStatus(F("ERR"), F("quick_tare_timeout"));
      digitalWrite(led1Pin, LOW);
      return;
    }
    delay(2);
  }

  tareValue = loadCell.read_average(8);
  hasLoadSample = false;
  hasFilteredLoadSample = false;
  lastLoadValue = 0.0f;
  lastRawLoadValue = 0.0f;
  hx711RawWindowCount = 0;
  hx711RawWindowIndex = 0;
  lastHx711DataMs = millis();
  digitalWrite(led1Pin, LOW);
}

float computeMedian(const float *values, uint8_t count) {
  if (count == 0) {
    return 0.0f;
  }

  float sorted[hx711MedianWindowSize];
  for (uint8_t i = 0; i < count; i++) {
    sorted[i] = values[i];
  }

  for (uint8_t i = 1; i < count; i++) {
    float value = sorted[i];
    int8_t j = (int8_t)i - 1;
    while (j >= 0 && sorted[j] > value) {
      sorted[j + 1] = sorted[j];
      j--;
    }
    sorted[j + 1] = value;
  }

  if ((count & 0x01) == 1) {
    return sorted[count / 2];
  }
  return 0.5f * (sorted[(count / 2) - 1] + sorted[count / 2]);
}

float getMedianFilteredLoad(float measuredLoad) {
  hx711RawWindow[hx711RawWindowIndex] = measuredLoad;
  hx711RawWindowIndex = (uint8_t)((hx711RawWindowIndex + 1) % hx711MedianWindowSize);
  if (hx711RawWindowCount < hx711MedianWindowSize) {
    hx711RawWindowCount++;
  }

  float orderedWindow[hx711MedianWindowSize];
  for (uint8_t i = 0; i < hx711RawWindowCount; i++) {
    uint8_t sourceIndex = (uint8_t)((hx711RawWindowIndex + hx711MedianWindowSize - hx711RawWindowCount + i) % hx711MedianWindowSize);
    orderedWindow[i] = hx711RawWindow[sourceIndex];
  }
  return computeMedian(orderedWindow, hx711RawWindowCount);
}

bool isGainPlausible(float gain) {
  if (!isfinite(gain)) {
    return false;
  }
  float absGain = fabs(gain);
  return absGain >= gainAbsMin && absGain <= gainAbsMax;
}

bool isGainWriteWindowActive() {
  if (!gainWriteArmed) {
    return false;
  }
  unsigned long nowMs = millis();
  if ((long)(gainWriteAllowedUntilMs - nowMs) <= 0) {
    gainWriteArmed = false;
    return false;
  }
  return (long)(nowMs - gainWriteAllowedFromMs) >= 0;
}

void processSerial() {
  while (Serial.available() > 0) {
    char c = (char)Serial.read();
    if (c == '\r') {
      continue;
    }
    if (c == '\n') {
      if (serialLineIndex > 0) {
        serialLine[serialLineIndex] = '\0';
        processCommand(serialLine);
        serialLineIndex = 0;
      }
      continue;
    }
    if (serialLineIndex < sizeof(serialLine) - 1) {
      serialLine[serialLineIndex++] = c;
    }
  }
}
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

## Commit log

2019-02-02 Gathering files
    [DistanceGauge.stl, FilamentClamp.stl, LayerAdhesionSpecimenAlignmentTool.stl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]
2019-02-02 furter update
    [OpenPull.fzz]
2019-02-03 warning added
    [OpenPull.fzz]
2019-02-16 Added CAD files
    [OpenPull-assembly.f3d, OpenPull-assembly.step, TensileTestMachine v6_TensileTestMachine v6_ClampingYaw1_1_608 bearing_1_Body1_608 bearing.stl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]
2019-02-17 Added a function to print empty lines.
    Added a new function that will print a given amount of empty lines and replaced repetitive code with that function.
    [OpenPull.ino]
2019-05-08 Create PCB
    Make Library, Schematic, Board and README
    [schematic.brd, schematic.sch]
2026-02-20 added webGui and improved arduino code
2026-02-21 Add relative movement commands and enhance WebGUI controls for speed and sample rate
2026-02-21 Add preload and filter alpha configuration to WebGUI and firmware
2026-02-21 Implement median filtering for load measurements and adjust preload handling in WebGUI
2026-02-22 Add auto break detection feature and enhance sample modal in WebGUI
2026-02-23 Add sample material input and summary display; implement test deletion functionality
